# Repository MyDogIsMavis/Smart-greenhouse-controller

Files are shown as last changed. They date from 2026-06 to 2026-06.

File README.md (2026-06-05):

# Smart Greenhouse Controller

Custom greenhouse monitoring and control system based on Arduino Nano and a custom PCB designed in Altium Designer.

The project was initially designed as a flexible greenhouse controller platform with support for multiple sensors and real-time information display on a TFT screen.

The system provides automatic temperature and lighting control with configurable day/night operating modes, TFT user interface and EEPROM-based persistent settings storage.

The project was developed as a practical greenhouse automation solution with potential future commercial application.

The controller is currently deployed in a real greenhouse environment.

# Table of Contents

* [Features](#features)
* [PCB Design](#pcb-design)
* [Power Supply Design](#power-supply-design)
* [Relay Control and Isolation](#relay-control-and-isolation)
* [Firmware](#firmware)
* [Hardware Overview](#hardware-overview)
* [User Interface](#user-interface)
* [Repository Structure](#repository-structure)
* [Current Status](#current-status)
* [Future Improvements](#future-improvements)

## Features

* Day/night operating modes
* Configurable temperature thresholds
* Hysteresis-based heating control
* Automatic and manual light control
* RTC-based scheduling
* TFT graphical user interface
* EEPROM settings storage
* Button-controlled menu navigation
* DS18B20 temperature monitoring
* Relay-controlled heating and lighting outputs

## PCB Design

The PCB was designed and routed in Altium Designer.

Main design goals:

* compact standalone controller design
* galvanic isolation of relay circuits
* onboard AC/DC power conversion
* simple external wiring
* support for future hardware expansion

The current stable hardware revision:

* v2 - stable working revision currently operating in greenhouse conditions

<p align="center">
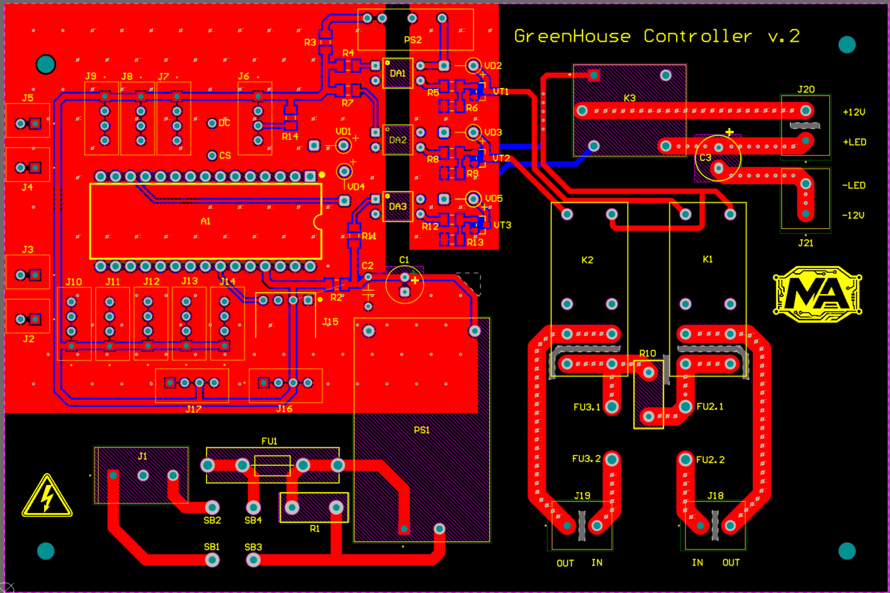
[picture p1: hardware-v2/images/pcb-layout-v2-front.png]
  
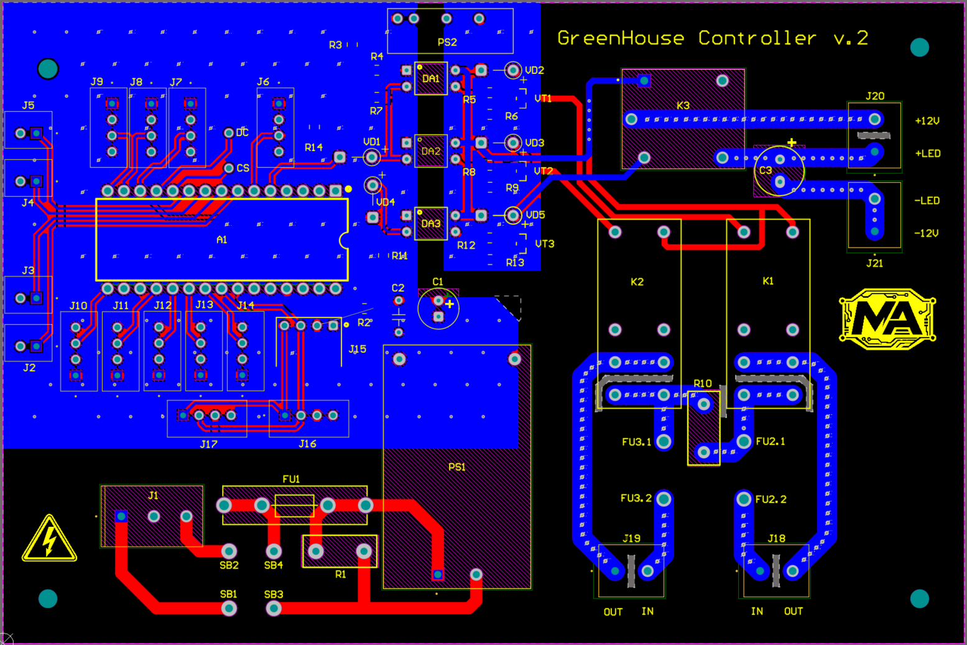
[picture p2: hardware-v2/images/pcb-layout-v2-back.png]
  
</p>

<p align="center">
  Front side (left) and back side (right) of the PCB in Altium Designer.
</p>

Future hardware revision:

* v3-development - optimized connector layout, reduced number of unused interfaces and improved PCB routing

## Power Supply Design

The controller includes an onboard AC/DC power supply based on the Hi-Link HLK-5M05 module (220 VAC to 5 VDC, 5 W).
The input power stage includes:

* 5x20 fuse protection
* MOV surge suppression (10K471 varistor)
* output filtering capacitors

## Relay Control and Isolation

Relay control circuits are optically isolated from the microcontroller.

Additional galvanic isolation between the microcontroller and relay power domains is implemented using the B0505S-3WR2 isolated DC/DC converter.

Separate ground domains are used for:

* microcontroller logic
* relay power and switching circuits

All relay driver circuits were designed and routed independently using discrete MOSFET stages instead of prebuilt relay modules.

Heating control is implemented using dual SMIH-05VDC-SL-C relays for simultaneous switching of phase and neutral lines.

Additional heater load protection is implemented using dual line fuses and a MOV surge suppressor connected across the heater output lines.

The maximum heater power is intentionally limited to approximately 2200 W to reduce relay contact stress and improve long-term reliability.

Lighting control uses SRD-05VDC-SL-C relays for switching external 12 V LED power supplies.

## Firmware

The firmware was developed in Arduino IDE and implements:

* menu navigation system
* sensor polling
* RTC scheduling
* EEPROM configuration storage
* hysteresis control logic
* debounced button input handling
* editable user settings interface

The firmware uses persistent EEPROM storage to retain user settings after power loss.

## Hardware Overview

Main hardware components:

* Arduino Nano
* Custom PCB designed in Altium Designer
* 128x160 SPI TFT display based on ST7735 controller
* DS18B20 temperature sensor
* DS3231 RTC module
* Relay-controlled outputs
* LDR-based light sensor module

The PCB was professionally manufactured and implemented as a standalone greenhouse controller.

<p align="center">
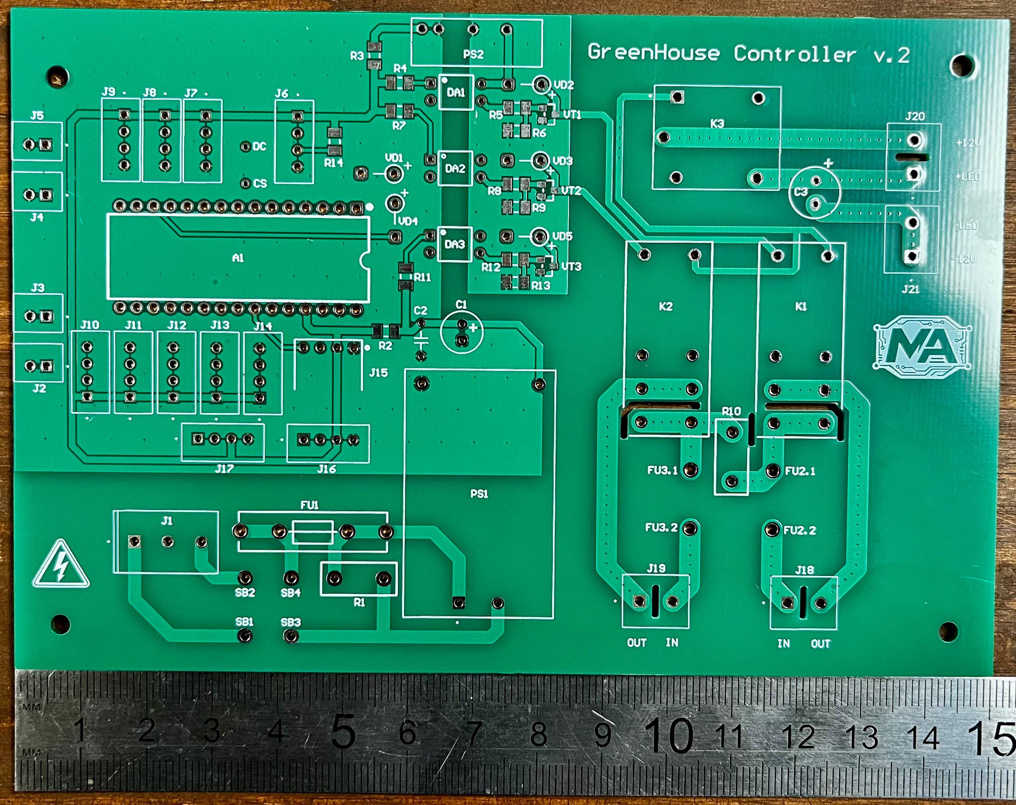
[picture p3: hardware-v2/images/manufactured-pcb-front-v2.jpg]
  
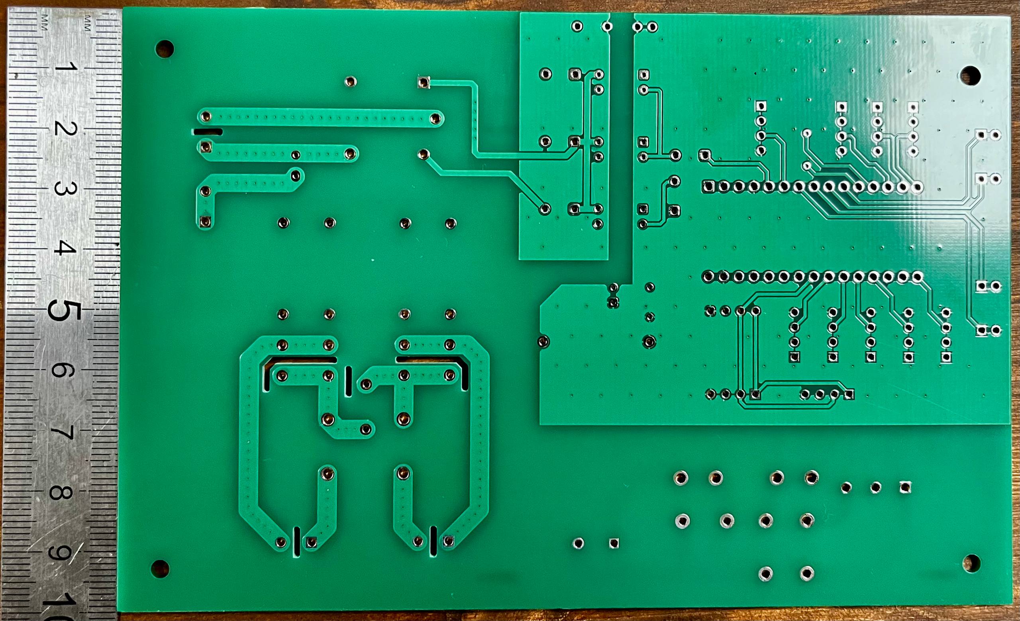
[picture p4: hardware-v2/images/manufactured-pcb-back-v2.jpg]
  
</p>

<p align="center">
  Front side (left) and back side (right) of the manufactured PCB.
</p>

## User Interface

The controller uses a simple TFT-based graphical interface navigated using hardware buttons.

The interface allows:

* real-time monitoring of temperature and RTC time
* configuration of day/night operating schedules
* adjustment of heating hysteresis thresholds
* manual and sensor-based lighting control
* status indication for heating and lighting outputs

The lighting control system supports both:

* automatic sensor-based operation
* manual ON/OFF override mode

<p align="center">
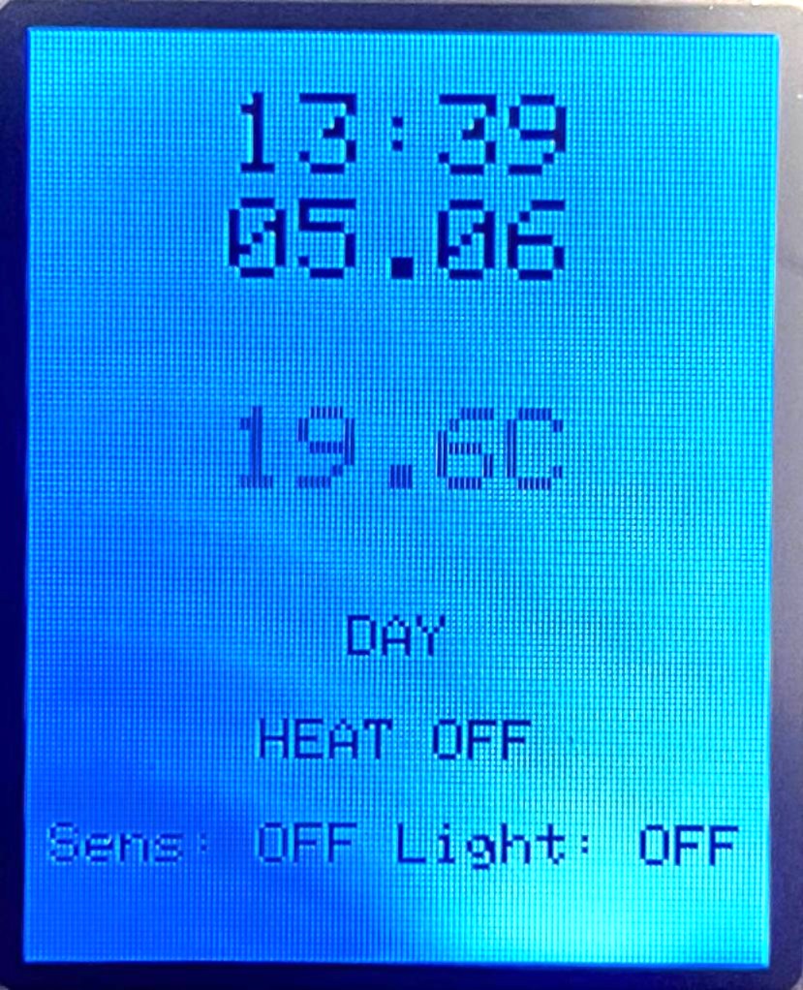
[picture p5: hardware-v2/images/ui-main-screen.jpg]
  
</p>
<p align="center">
  Main operating screen displaying current temperature, current time and output status
</p>

<p align="center">
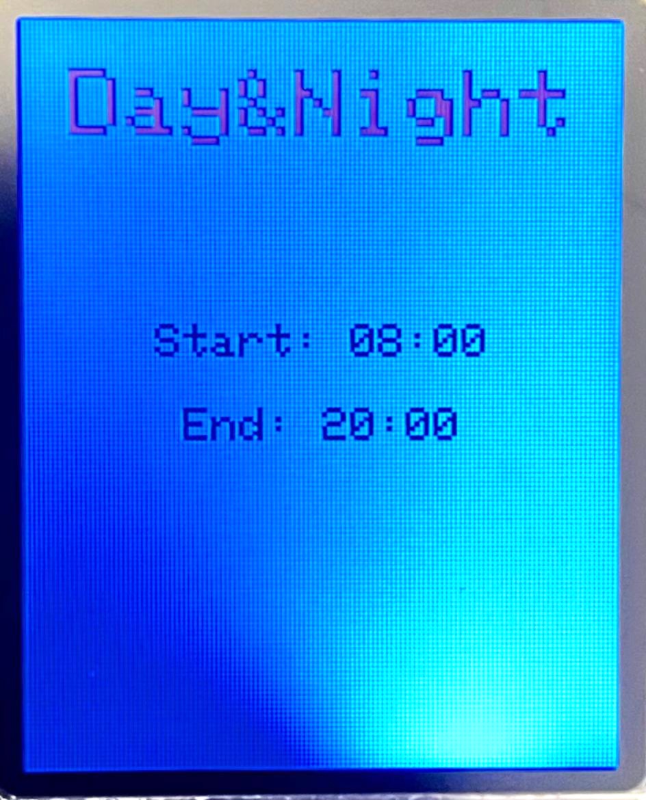
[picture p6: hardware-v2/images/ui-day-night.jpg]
  
</p>
<p align="center">
  Day/Night scheduling screen with configurable operating time settings.
</p>

<p align="center">
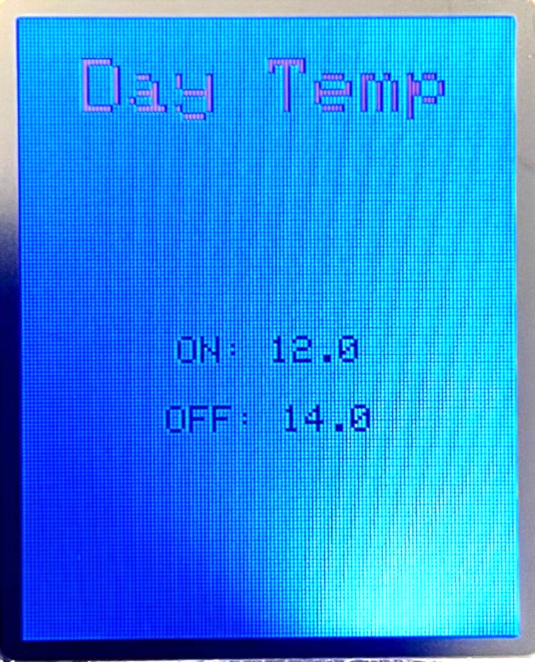
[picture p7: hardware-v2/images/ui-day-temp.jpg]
  
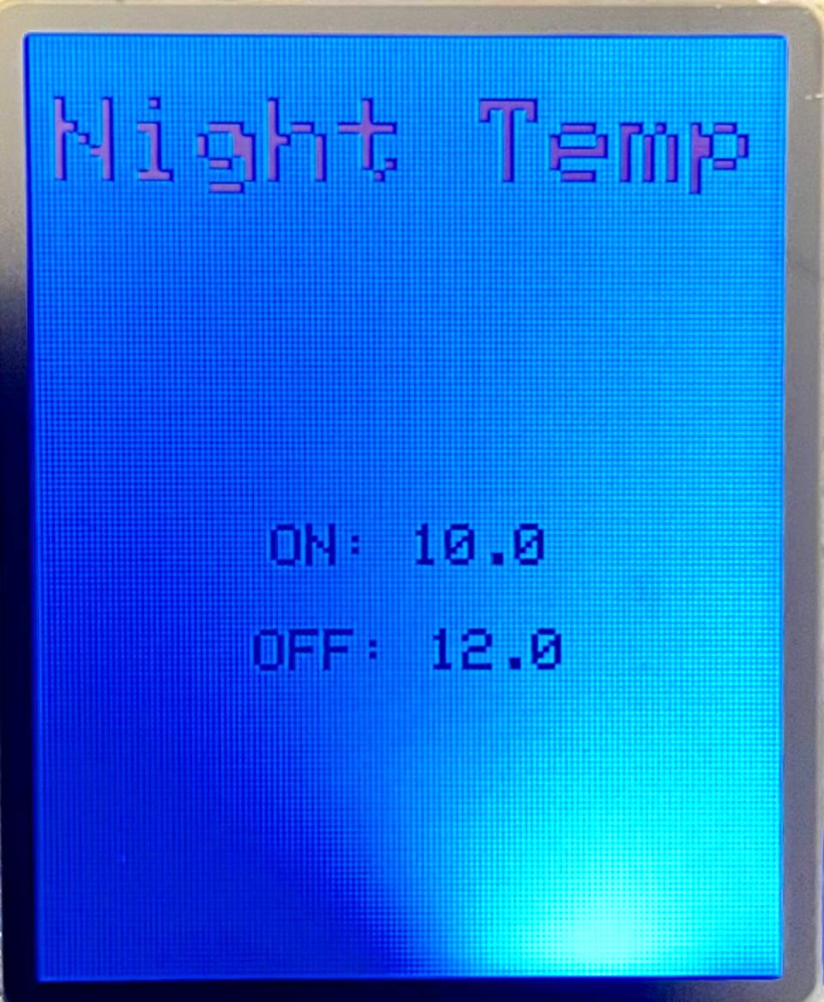
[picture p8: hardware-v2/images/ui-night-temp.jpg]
  
</p>
<p align="center">
  This screen displays configurable ON/OFF temperature thresholds for heater operation in day and night modes
</p>

<p align="center">
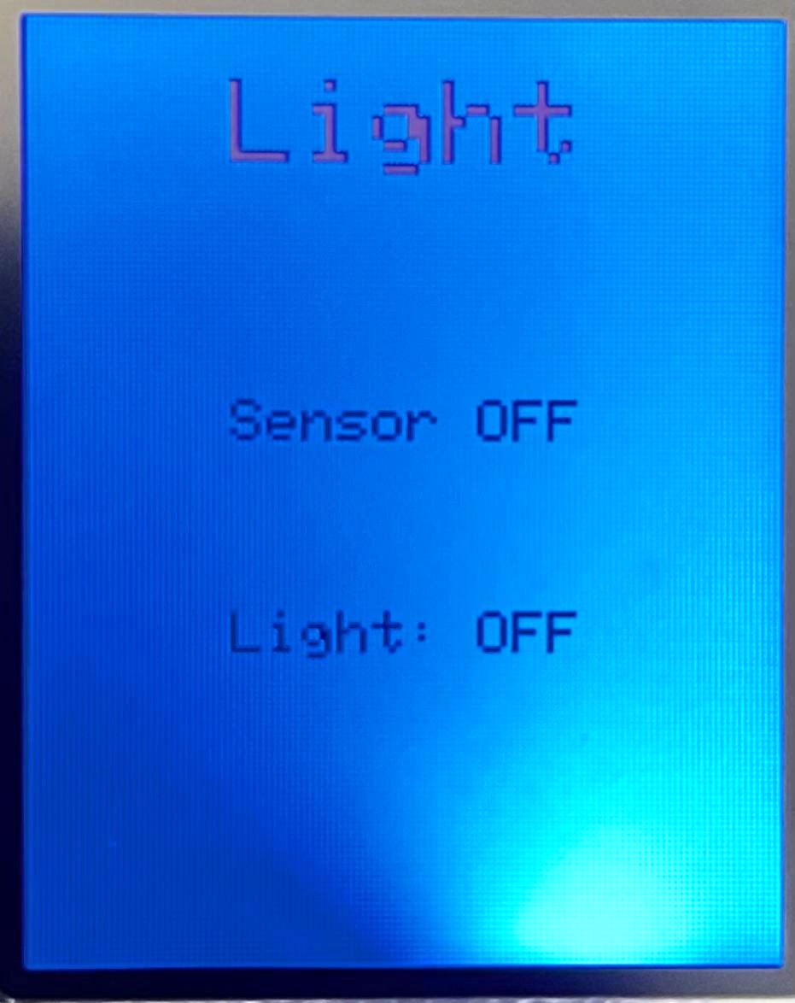
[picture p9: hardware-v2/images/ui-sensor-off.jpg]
  
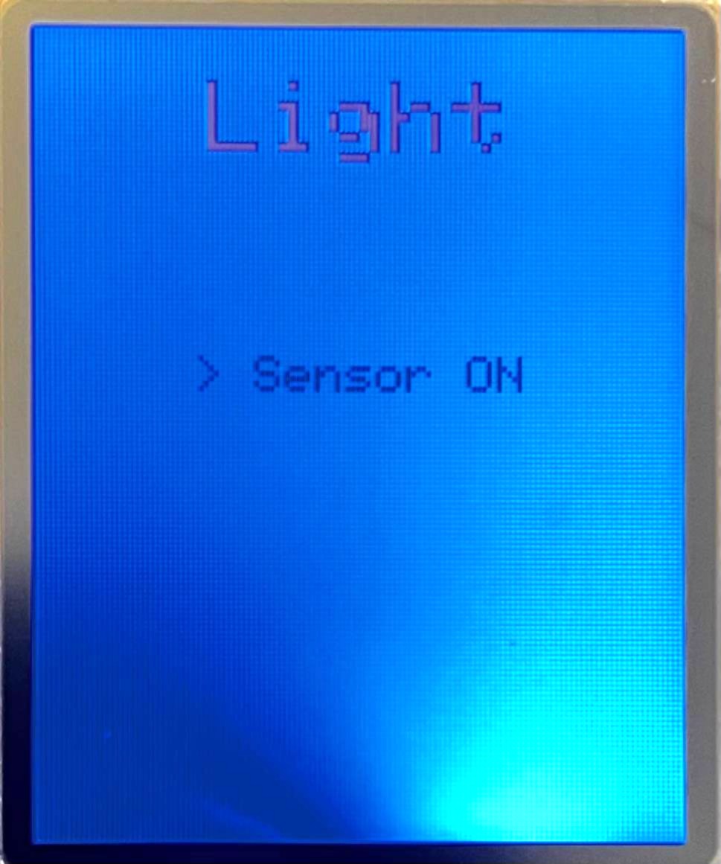
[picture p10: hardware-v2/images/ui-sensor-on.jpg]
  
</p>

<p align="center">
  This screen displays light sensor status and allows switching between manual and sensor-based lighting control modes
</p>

## Repository Structure

* hardware-v2 - stable hardware revision
* hardware-v3-development - next hardware revision containing files related to ongoing development and PCB optimization.

## Current Status

The current hardware revision has been operating continuously in a greenhouse environment for over a month without critical issues.

The project is currently in the testing and optimization stage before further hardware refinement and production-oriented improvements.

## Future Improvements

Planned improvements:

* optimized PCB routing
* reduced number of unused interfaces
* enclosure redesign
* simplified assembly process
* preparation for future small-scale production
* migration to ESP32-based hardware platform with wireless connectivity
* remote greenhouse monitoring and climate control via Wi-Fi
* integration of automated irrigation control
* support for pump and electromechanical valve control
* support for additional environmental sensors such as humidity monitoring
* further PCB optimization based on practical deployment experience

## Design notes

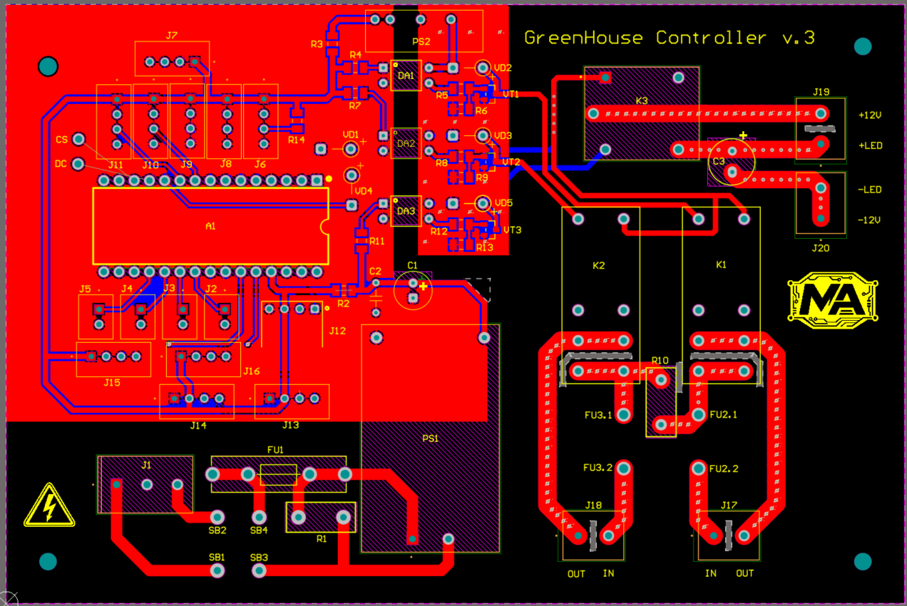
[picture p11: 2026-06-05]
hardware-v3-dev/images/pcb-layout-v3-front.png

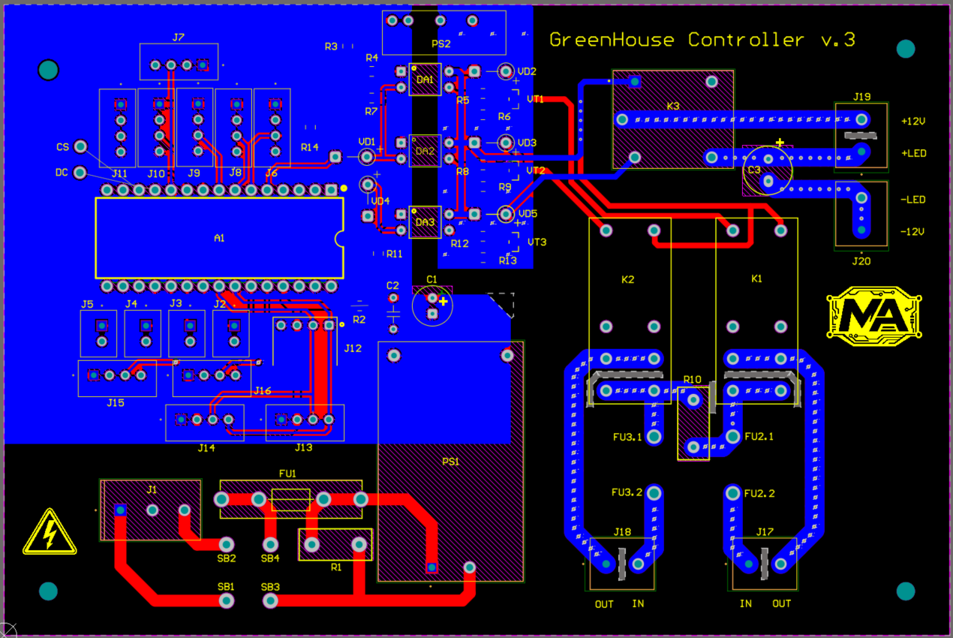
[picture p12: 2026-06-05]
hardware-v3-dev/images/pcb-layout-v3-back.png

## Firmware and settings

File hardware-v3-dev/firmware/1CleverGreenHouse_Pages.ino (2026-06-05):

#include <EEPROM.h>
#include <Arduino.h>
#include <Adafruit_GFX.h>
#include <Adafruit_ST7735.h>
#include <SPI.h>
#include <Wire.h>
#include <OneWire.h>
#include <DallasTemperature.h>
#include <RTClib.h>

// ===== TFT =====
#define TFT_CS   8
#define TFT_DC   9
#define TFT_RST  -1   // через ICSP RESET

Adafruit_ST7735 tft = Adafruit_ST7735(TFT_CS, TFT_DC, TFT_RST);

// ===== BUTTONS =====
#define BTN_MODE 4
#define BTN_NEXT 5
#define BTN_PLUS 6
#define BTN_MINUS 7

#define RELAY_PIN 2
#define ONE_WIRE_BUS 3
#define LDR_PIN A1
#define LIGHT_RELAY_PIN 10

struct Button {
  uint8_t pin;

  bool state;
  bool prevState;
  bool lastReading;

  unsigned long lastDebounce;

  bool lock;

  // hold repeat
  unsigned long holdStart;
  unsigned long lastRepeat;
};

Button btnMode  = {BTN_MODE, HIGH, HIGH, HIGH, 0, false, 0, 0};
Button btnNext  = {BTN_NEXT, HIGH, HIGH, HIGH, 0, false, 0, 0};
Button btnPlus  = {BTN_PLUS, HIGH, HIGH, HIGH, 0, false, 0, 0};
Button btnMinus = {BTN_MINUS, HIGH, HIGH, HIGH, 0, false, 0, 0};

void updateButton(Button &b) {
  bool r = digitalRead(b.pin);
  if (r != b.lastReading) b.lastDebounce = millis();
  if (millis() - b.lastDebounce > 30) {
    b.prevState = b.state;
    b.state = r;
  }
  b.lastReading = r;
}

bool pressed(Button &b) {

  if (b.prevState == HIGH &&
      b.state == LOW &&
      !b.lock) {

    b.lock = true;
    return true;
  }

  if (b.state == HIGH)
    b.lock = false;

  return false;
}
bool repeatPressed(Button &b){

  // обычное нажатие
  if(pressed(b)){

    b.holdStart = millis();
    b.lastRepeat = millis();

    return true;
  }

  // удержание
  if(b.state == LOW){

    // ждём 1.5 секунды
    if(millis() - b.holdStart > 1500){

      // повтор каждые 120 мс
      if(millis() - b.lastRepeat > 120){

        b.lastRepeat = millis();

        return true;
      }
    }
  }

  return false;
}

// ===== SENSORS =====
OneWire oneWire(ONE_WIRE_BUS);
DallasTemperature sensors(&oneWire);
RTC_DS3231 rtc;

// SETTINGS
float dayOn=22, dayOff=24;
float nightOn=20, nightOff=22;
int dayStartH=8;
int dayStartM=0;
int dayEndH=22;
int dayEndM=0;
int dayStartH_e;
int dayStartM_e;
int dayEndH_e;
int dayEndM_e;


struct Settings {

  uint16_t magic;

  float dayOn;
  float dayOff;

  float nightOn;
  float nightOff;

  int dayStartH;
  int dayStartM;

  int dayEndH;
  int dayEndM;

  bool sensorEnabled;
};

Settings settings;

// LIGHT
bool sensorEnabled=true;
bool lightState=false;


void loadSettings(){

  EEPROM.get(0, settings);

  // защита от мусора EEPROM
 if(settings.magic != 0xBEEF){

    settings.magic = 0xBEEF;

    settings.dayOn = 8;
    settings.dayOff = 10;

    settings.nightOn = 8;
    settings.nightOff = 10;

    settings.dayStartH = 8;
    settings.dayStartM = 1;

    settings.dayEndH = 22;
    settings.dayEndM = 1;

    settings.sensorEnabled = true;

    EEPROM.put(0, settings);
}

  // перенос в рабочие переменные
  dayOn = settings.dayOn;
  dayOff = settings.dayOff;

  nightOn = settings.nightOn;
  nightOff = settings.nightOff;

  dayStartH = settings.dayStartH;
  dayStartM = settings.dayStartM;

  dayEndH = settings.dayEndH;
  dayEndM = settings.dayEndM;

  sensorEnabled = settings.sensorEnabled;
}
void saveSettings(){

  settings.magic = 0xBEEF;
  settings.dayOn = dayOn;
  settings.dayOff = dayOff;

  settings.nightOn = nightOn;
  settings.nightOff = nightOff;

  settings.dayStartH = dayStartH;
  settings.dayStartM = dayStartM;

  settings.dayEndH = dayEndH;
  settings.dayEndM = dayEndM;

  settings.sensorEnabled = sensorEnabled;

  EEPROM.put(0, settings);
}


// EDIT
float dOn_e, dOff_e, nOn_e, nOff_e;


// STATE
float temp=0;
bool relay=false;

int screen=0;
bool editMode=false;
int editField=0;

// TIMERS
unsigned long sensorTimer=0;
unsigned long screenTimer=0;

// HOLD
unsigned long bothTime=0;
bool bothHold=false;

String prev[8];

String two(int v){return (v<10?"0":"")+String(v);}

void draw(int i,String t,int s,uint16_t c){
  if(prev[i]!=t){
    prev[i]=t;
    int y=10+i*18;
    tft.fillRect(0,y,128,18,ST77XX_WHITE);
    tft.setTextSize(s);
    tft.setTextColor(c);

    int16_t x1, y1;
    uint16_t w, h;
    tft.getTextBounds(t, 0, y, &x1, &y1, &w, &h);
    int x = (128 - w) / 2;

    tft.setCursor(x, y);
    tft.print(t);
  }
}

void clearAll(){
  for(int i=0;i<8;i++) prev[i]="";
  tft.fillScreen(ST77XX_WHITE);
}

// ===== SETUP =====
void setup(){

  // ===== SPI FIX =====
  // D10 обязательно должен быть OUTPUT
  // иначе SPI может сломаться
  pinMode(10, OUTPUT);

  // выключаем реле света
  digitalWrite(10, HIGH);

  delay(50);

  // ===== TFT =====
  tft.initR(INITR_BLACKTAB);
  tft.fillScreen(ST77XX_WHITE);

  // тест
  tft.setTextColor(ST77XX_BLACK);
  tft.setTextSize(2);
  tft.setCursor(10,20);
  tft.print("BOOT");

  // ===== SENSORS =====
  sensors.begin();
  loadSettings();

  // ===== RTC =====
  rtc.begin();
  //rtc.adjust(DateTime(F(__DATE__),F(__TIME__)));

  // ===== HEAT RELAY =====
  pinMode(RELAY_PIN, OUTPUT);
  digitalWrite(RELAY_PIN, HIGH);

  // ===== LIGHT RELAY =====
  pinMode(LIGHT_RELAY_PIN, OUTPUT);
  digitalWrite(LIGHT_RELAY_PIN, HIGH);

  // ===== BUTTONS =====
  pinMode(BTN_MODE, INPUT_PULLUP);
  pinMode(BTN_NEXT, INPUT_PULLUP);
  pinMode(BTN_PLUS, INPUT_PULLUP);
  pinMode(BTN_MINUS, INPUT_PULLUP);

  delay(500);

  clearAll();

}
// ===== LOOP =====
void loop(){

  DateTime now=rtc.now();

  updateButton(btnMode);
  updateButton(btnNext);
  updateButton(btnPlus);
  updateButton(btnMinus);

  if(millis()-sensorTimer>2000){
    sensors.requestTemperatures();
    temp=sensors.getTempCByIndex(0);
    sensorTimer=millis();
  }

int nowMinutes =
    now.hour() * 60 +
    now.minute();

int startMinutes =
    dayStartH * 60 +
    dayStartM;

int endMinutes =
    dayEndH * 60 +
    dayEndM;

bool isDay;

if(startMinutes < endMinutes){

  // обычный режим
  // например 08:00 -> 22:00
  isDay =
    nowMinutes >= startMinutes &&
    nowMinutes < endMinutes;

} else {

  // диапазон через полночь
  // например 22:00 -> 08:00
  isDay =
    nowMinutes >= startMinutes ||
    nowMinutes < endMinutes;
}

  float tOn=isDay?dayOn:nightOn;
  float tOff=isDay?dayOff:nightOff;

  if(temp==-127){
    digitalWrite(RELAY_PIN,HIGH);
    relay=false;
  } else {
    if(temp<=tOn && !relay){digitalWrite(RELAY_PIN,LOW);relay=true;}
    if(temp>=tOff && relay){digitalWrite(RELAY_PIN,HIGH);relay=false;}
  }

  if(sensorEnabled){
    
    int lightThreshold=500;//задаем порог включения света

    lightState=(analogRead(LDR_PIN)<lightThreshold);
  }
//реле света
digitalWrite(
  LIGHT_RELAY_PIN,
  lightState ? LOW : HIGH
); 

  if(pressed(btnNext)){
    if(!editMode){
      editMode=true;
      editField=0;
      dOn_e=dayOn; dOff_e=dayOff;
      nOn_e=nightOn; nOff_e=nightOff;
      dayStartH_e = dayStartH;
dayStartM_e = dayStartM;
dayEndH_e = dayEndH;
dayEndM_e = dayEndM;
    } else {
editField++;

if(screen==1){
  if(editField>3) editField=0;
} else {
  if(editField>1) editField=0;
}
    }
    clearAll();
  }

  if(btnPlus.state==LOW && btnMinus.state==LOW){
    if(!bothHold){
      bothHold=true;
      bothTime=millis();
    }
    if(millis()-bothTime>3000 && editMode){
      dayOn=dOn_e; dayOff=dOff_e;
      nightOn=nOn_e; nightOff=nOff_e;
      dayStartH = dayStartH_e;
dayStartM = dayStartM_e;

dayEndH = dayEndH_e;
dayEndM = dayEndM_e;
saveSettings();
      editMode=false;
      clearAll();
      bothHold=false;
    }
  } else {
    bothHold=false;
  }

if(pressed(btnMode)){

  // CANCEL edit mode
  if(editMode){

    editMode = false;
    clearAll();
  }
  else{

    screen++;

    if(screen>4)
      screen=0;

    clearAll();
  }
}

  if(editMode){

if(screen==1){

if(repeatPressed(btnPlus)){

  if(editField==0 && dayStartH_e<23)
    dayStartH_e++;

  if(editField==1 && dayStartM_e<59)
    dayStartM_e++;

  if(editField==2 && dayEndH_e<23)
    dayEndH_e++;

  if(editField==3 && dayEndM_e<59)
    dayEndM_e++;
}

  if(repeatPressed(btnMinus)){

  if(editField==0 && dayStartH_e>0)
    dayStartH_e--;

  if(editField==1 && dayStartM_e>0)
    dayStartM_e--;

  if(editField==2 && dayEndH_e>0)
    dayEndH_e--;

  if(editField==3 && dayEndM_e>0)
    dayEndM_e--;
}
}

    if(screen==2){
      if(repeatPressed(btnPlus)){
        if(editField==0 && dOn_e+1<dOff_e) dOn_e++;
        if(editField==1) dOff_e++;
      }
      if(repeatPressed(btnMinus)){
        if(editField==0) dOn_e--;
        if(editField==1 && dOff_e-1>dOn_e) dOff_e--;
      }
    }

    if(screen==3){
      if(repeatPressed(btnPlus)){
        if(editField==0 && nOn_e+1<nOff_e) nOn_e++;
        if(editField==1) nOff_e++;
      }
      if(repeatPressed(btnMinus)){
        if(editField==0) nOn_e--;
        if(editField==1 && nOff_e-1>nOn_e) nOff_e--;
      }
    }

    if(screen==4){
      if(editField==0){
        if(repeatPressed(btnPlus) && !sensorEnabled){
    sensorEnabled=true;
    saveSettings();
}
if(repeatPressed(btnMinus) && sensorEnabled){
    sensorEnabled=false;
    lightState=false;
    saveSettings();
}
      }

      if(!sensorEnabled && editField==1){
        if(repeatPressed(btnPlus) && !lightState) lightState=true;
        if(repeatPressed(btnMinus) && lightState) lightState=false;
      }
    }
  }

  if(millis()-screenTimer>200){
    screenTimer=millis();

    if(screen==0){
      draw(0,two(now.hour())+":"+two(now.minute()),2,ST77XX_BLACK);
      draw(1,two(now.day())+"."+two(now.month()),2,ST77XX_BLACK);
      draw(3,String(temp,1)+"C",2,ST77XX_BLUE);
      draw(5,isDay?"DAY":"NIGHT",1,ST77XX_BLACK);
      draw(6,relay?"HEAT ON":"HEAT OFF",1,ST77XX_BLACK);
      draw(7,
        String("Sens: ")+(sensorEnabled?"ON":"OFF")+
        " Light: "+(lightState?"ON":"OFF"),
        1,ST77XX_BLACK);
    }

if(screen==1){

  draw(0,"Day&Night",2,ST77XX_RED);

String s1;
String s2;

if(editMode){

  s1 =
    "Start: " +
    two(dayStartH_e) +
    ":" +
    two(dayStartM_e);

  s2 =
    "End: " +
    two(dayEndH_e) +
    ":" +
    two(dayEndM_e);

} else {

  s1 =
    "Start: " +
    two(dayStartH) +
    ":" +
    two(dayStartM);

  s2 =
    "End: " +
    two(dayEndH) +
    ":" +
    two(dayEndM);
}

  uint16_t c1 = ST77XX_BLACK;
  uint16_t c2 = ST77XX_BLACK;

  // Start hours
  if(editMode && editField==0)
    c1 = ST77XX_BLUE;

  // Start minutes
  if(editMode && editField==1)
    c1 = ST77XX_BLUE;

  // End hours
  if(editMode && editField==2)
    c2 = ST77XX_BLUE;

  // End minutes
  if(editMode && editField==3)
    c2 = ST77XX_BLUE;

  draw(3,s1,1,c1);
  draw(4,s2,1,c2);
}

if(screen==2){

  draw(0,"Day Temp",2,ST77XX_RED);

  String a;
  String b;

  if(editMode){

    a="ON: "+String(dOn_e,1);
    b="OFF: "+String(dOff_e,1);

  } else {

    a="ON: "+String(dayOn,1);
    b="OFF: "+String(dayOff,1);
  }

  if(editMode && editField==0)
    a="> "+a;

  if(editMode && editField==1)
    b="> "+b;

  draw(4,a,1,
      (editMode && editField==0)?
      ST77XX_BLUE:ST77XX_BLACK);

  draw(5,b,1,
      (editMode && editField==1)?
      ST77XX_BLUE:ST77XX_BLACK);
}

    if(screen==3){

  draw(0,"Night Temp",2,ST77XX_RED);

  String a;
  String b;

  if(editMode){

    a="ON: "+String(nOn_e,1);
    b="OFF: "+String(nOff_e,1);

  } else {

    a="ON: "+String(nightOn,1);
    b="OFF: "+String(nightOff,1);
  }

  if(editMode && editField==0)
    a="> "+a;

  if(editMode && editField==1)
    b="> "+b;

  draw(4,a,1,
      (editMode && editField==0)?
      ST77XX_BLUE:ST77XX_BLACK);

  draw(5,b,1,
      (editMode && editField==1)?
      ST77XX_BLUE:ST77XX_BLACK);
}


if(screen==4){

  draw(0,"Light",2,ST77XX_RED);

  String s="Sensor "+String(sensorEnabled?"ON":"OFF");

  if(editMode && editField==0)
    s="> "+s;

  draw(3,s,1,
      (editMode && editField==0)?
      ST77XX_BLUE:ST77XX_BLACK);

  if(!sensorEnabled){

    String l="Light: "+
      String(lightState?"ON":"OFF");

    if(editMode && editField==1)
      l="> "+l;

    draw(5,l,1,
        (editMode && editField==1)?
        ST77XX_BLUE:ST77XX_BLACK);

  } else {

    // очищаем старую строку
    prev[5]="";
    tft.fillRect(0,100,128,18,ST77XX_WHITE);
  }
}
  }
}

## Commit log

2026-06-05 Add smart greenhouse controller project
    [greenhouse_MA_2.PrjPcb, greenhouse_MA_2.SchDoc]
2026-06-05 Add hardware-v3-dev
    [greenhouse_MA_3.PrjPcb, greenhouse_MA_3.SchDoc]
